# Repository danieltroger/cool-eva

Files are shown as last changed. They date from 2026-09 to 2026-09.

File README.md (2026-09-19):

# Cool Eva

Telemetry for a **watercooled 2021 Energica Eva Ribelle**. A Raspberry Pi inside the bike logs the temperatures of a custom watercooling loop on the battery pack, **plus** the bike's own battery / charge / cell / drive telemetry read straight off the CAN bus — all into an encrypted, write-only ride log, surfaced as a live phone dashboard and (after decryption on the laptop) a Grafana dashboard for post-ride analysis.

## Hardware

- **Raspberry Pi Zero 2 W** running the app as a `systemd` service (Node.js, runs as root).
- **[8devices Korlan USB2CAN](https://shop.8devices.com/usb2can/korlan/)** plugged into the bike's OBD port → `can0` (in-kernel `usb_8dev`, no driver install). 500 kbit, 11-bit. The app reads broadcast frames _and_ actively polls standard OBD-II PIDs (**read-only** — no diagnostic writes).
- **2× MAX31865 + PT100 probes** over SPI — coolant **in** and **out** of the custom battery watercooling loop. **Optional**: this is the one piece of hardware most Energicas don't have. Without it everything else works and the coolant tiles simply don't appear.
- **Networking:** the Pi joins my **phone's hotspot**, so it's reachable at **`http://cool-eva.local`** from the phone's browser. It's a bit janky (have to open hotspot page in phone settings for ~20s at the start of every ride), but it works for an at-a-glance dash while riding/charging.

### If you have a stock Energica

The Korlan alone gets you most of this. Everything under [What it logs](#what-it-logs) works on a stock, unmodified bike except the sections explicitly marked otherwise — no watercooling loop, no probes and no BMS reflash required. Set `COOLANT_ENABLED=0` and the coolant probes are never attempted.

Two caveats worth knowing before you spend money:

- It is developed against a **2021 Eva Ribelle**. The pack shape is hardcoded in places — 81 cells in 11 modules, a 400 A discharge and 120 A regen ceiling, a 130 kW power bar — and nothing detects a mismatch. On another bike in the same pack family the readings are right and those scale limits may not be; on a differently-packed model (Experia) treat the whole thing as untested. Reports welcome. The **VCU parameter names are not** in that category any more: all 28 of Energica's parameter tables are shipped and the bike's own `TABLE_TYPE` picks one, so [that half works on your bike](#vcu-parameters-by-name) whichever it is — and if your table is newer than the 28, [adding it is one command](#adding-your-bikes-vcu-parameter-table).
- The bike's **CAN bus is not a toy**. This app only ever reads, but it does transmit standard OBD-II _read_ requests to do so (see [Notes](#notes)). If you would rather it never spoke at all, `OBD_ENABLED=0` makes it passive-only.

## Setup

From a blank SD card to a dashboard. Steps 1–5 are the Pi, step 6 is your laptop, and **step 6 is the one people skip and regret** — without it the dashboard works perfectly and nothing at all is saved.

**1. Flash Raspberry Pi OS (64-bit).** In Raspberry Pi Imager, open the gear icon and set:

- **hostname `cool-eva`** — this is what makes `http://cool-eva.local` work. Skip it and your Pi is `raspberrypi.local`.
- **Enable SSH**, with a password or your public key. There is no screen on the bike, so this is the only way in — including for every future update.
- **Wi-Fi: your phone's hotspot** (SSID and password), so it connects on the road. Add your home Wi-Fi too, from the Pi later, or you'll be swapping the card to get it back.

**2. Join the phone hotspot** (if you didn't set it in the Imager). Bookworm uses NetworkManager:

```bash
sudo nmcli device wifi connect "<your hotspot SSID>" password "<password>"
sudo nmcli connection modify "<your hotspot SSID>" connection.autoconnect yes
```

On iOS you have to **open Settings → Personal Hotspot and leave it on screen for ~20 s** at the start of a ride, or the phone won't accept the join. That is an iOS behaviour, not something this app can fix. The Pi Zero 2 W radio is **2.4 GHz only**, so a 5 GHz-only hotspot is invisible to it — on an iPhone 12 or later, Apple's own fix is Settings → Personal Hotspot → **Maximize Compatibility** — which Apple notes costs some hotspot speed and Wi-Fi security.

To add a **second** network later (home Wi-Fi, an Airbnb) while you are sshed in over the first, use `nmcli connection add` rather than `nmcli device wifi connect` — the latter activates what it creates and drops the session you are typing into. Exact command: [INSTALL.md §8](INSTALL.md).

**3. Install Node 24.** Raspberry Pi OS's `apt` Node is far too old — the app is TypeScript run directly, which needs `--experimental-strip-types` (Node 22.6.0 at the very oldest; 24 is what this is tested on).

```bash
curl -fsSL https://deb.nodesource.com/setup_24.x | sudo -E bash -
sudo apt install -y nodejs
node --version   # must be v22.6 or newer
```

**4. Clone and install.**

⚠️ **Give the Pi more swap first.** `npm install` compiles three native modules (`better-sqlite3`, `socketcan`, `spi-device`), which takes **several minutes** on a Pi Zero 2 W and wants more than the stock 512 MB — without it the build is OOM-killed and it looks like a crash rather than a memory problem. About 3 GB. How, for both Bookworm and Trixie: [INSTALL.md §2.5](INSTALL.md).

```bash
git clone https://github.com/<your-fork>/cool-eva.git ~/cool-eva
cd ~/cool-eva
npm install
```

Nothing else to do for those compiles: the repo ships an `.npmrc` allowlisting the four packages with install scripts, because **npm 12 and newer refuse to run them** otherwise and you get a tree with no `.node` files. Version boundaries, how to tell whether your modules actually built, and the measurements: [`docs/pi-install-prerequisites.md`](docs/pi-install-prerequisites.md).

**5. Only if you have the coolant probes: enable SPI.** `sudo raspi-config` → Interface Options → SPI → Yes, then reboot. **Don't enable it if you have no probes wired**: with SPI on and nothing attached the reads succeed and return −242 °C forever. The app notices and retires the probe after a minute, but it's noise you don't need.

**6. Generate the ride-log keypair — on your laptop, not the Pi.** Nothing is persisted until the Pi has a public key. See [Encrypted ride log](#encrypted-ride-log) for why it works this way.

```bash
# on the LAPTOP, in a clone of this repo
node --experimental-strip-types scripts/generate-log-key.ts
# back the PRIVATE key up now (password manager) — it is the only thing that
# can ever read your logs, and there is no recovery path
scp ride-log-key.public.pem pi@cool-eva.local:/home/pi/cool-eva/
```

**7. Install the service** (back on the Pi):

```bash
sudo $(which node) --experimental-strip-types scripts/setup-service.ts
sudo journalctl -u cool-eva -f    # follow the logs
```

The installer refuses to run on too-old a Node, removes the old `thermometer` unit if you're upgrading, and tells you if the ride-log key is still missing. In the log you want to see `ride-log: encrypting to …`; if you see the `NO PUBLIC KEY` banner instead, step 6 didn't land.

Then open **`http://cool-eva.local`** on your phone.

## What it logs

Everything is logged **on change** (so steady values don't spam the log) into the encrypted ride log — see [Encrypted ride log](#encrypted-ride-log).

| Group | Signals | Source |
| --- | --- | --- |
| **Coolant** (custom loop) | `coolant_in`, `coolant_out` (°C) | MAX31865 PT100 |
| **Cooling fan** (custom loop, `FAN_ENABLED=1`) | `fan_duty_pct` (%, what the bridge is being given), `fan_target_pct` (%, what was asked for — the two differ only during a kick-start), `fan_driver_enabled` (1 = both IBT-2 enables HIGH, 0 = standby), plus `fan_auto_mode` (1 = the temperature curve is driving, 0 = the slider is) and the two codes that say why the curve chose what it chose, `fan_auto_reason` and `fan_temp_input`. Every one is what the Pi **commanded or decided**, never what it measured: this fan has no tacho and the current-sense pins are unconnected, so nothing here can tell you the rotor is actually turning. Written on change like everything else, which for a fan held at one duty means nothing for an hour. See [`docs/fan-control.md`](docs/fan-control.md) | Pi hardware PWM0 + `pinctrl` |
| **Battery / BMS** | `batt_temp_lo`, `batt_temp_hi` (°C, always the **true** pack temperature), `batt_temp_lo_vcu`, `batt_temp_hi_vcu` (what the VCU and dash read — lowered once a DC-derate config is flashed, by an amount that depends on the config; under the current bounded clamp they read 35 °C throughout the 35–54 °C band and the true temperature either side of it), `soc` (%), `soh` (%), `pack_v` (V), `pack_a` (A), `pack_kw` (kW), `allowed_discharge_a`, `allowed_regen_a` (A), `pack_resistance_mohm` (mΩ) | CAN `0x200`/`0x202`/`0x206`/`0x660` |
| **Cells** | `cell_min_mv`, `cell_avg_mv`, `cell_max_mv`, `cell_spread_mv`, `cell_deviation_mv` (the BMS's own ΔV), `cell_lowest_v_idx`, `cell_highest_v_idx` (which cell is at each extreme _right now_ — at a few mV of spread that ranking is noise, not a health verdict), `cells_connected`, `cell_voltage_sum_v` | CAN `0x203`/`0x205`/`0x207` |
| **BMS state & faults** | `charge_state` (raw System State bitfield) + decoded `bms_state_*` (discharge / charge / balancing / trickle / idle / charge complete / maintenance), `bms_error_flags`, `bms_warning_flags` (raw words) + booleans for the ones worth acting on: cell over/under voltage, over temperature, leak detected, leak detection failed, contactor faults, low SOC, balancing required. Plus `bms_leak_detect_inhibit` — Energica's own `V_IMD_DISABLE`, the vehicle **commanding** the insulation monitor off for the duration of a DC session, since it cannot run against a station-driven bus. It is 1 while a DC session exists in 99.933 % of 156 931 frames and 0 whenever one does not in 100.000 % of 810 934 | CAN `0x201`/`0x605` b7 |
| **Isolation** | `iso_test_1`, `iso_test_2`, `iso_test_total` (10-bit ADC, 512 = ideal), `bms_io_state`, `lmu_comm_warnings` | CAN `0x207`/`0x206` |
| **Charge** | `charge_state`, `dc_v`, `dc_a`, `mains_v`, `mains_a`, `charge_limit_a`, `dc_charge_limit_selected_a`, `charger_enabled`, `charger_max_dc_v`, `charger_max_dc_a`, `bms_post_processor_1` (purpose unknown, logged raw so a ride can name it), `fast_dc_contactor` — the DC fast-charge contactor monitor (Energica's `V_FASTDC_MON_SW`, and the analog wire `A020_FCHG_MON`). It is 1 only on DC: across 1.1 M frames of `0x102` it was set in exactly one interval, a 17-minute DC session that took the pack 30 → 42 %, and 0 through every AC charge including a 48-minute one at 14 A. It rises ~190 ms before `charger_enabled` and ~470 ms before the first amp, which is what a contactor monitor should do. **From the charge manager** (decoded 2026-08-19 across 29 charge sessions, 18 AC and 11 DC — that ECU is only awake with a cable plugged in, and the standing assumption that this meant DC only was wrong; reconciled against Energica's factory DBC on 2026-08-20, see `docs/charge-manager.md`): `fast_dc_target_a` — the DC current the vehicle **asks the station for**, and the only DC-side current on this bus, since a DC session sends no `0x305`/`0x306` at all and `charge_limit_a` reads 0 through one; `fast_dc_target_v`, the DC target voltage that goes with it, which sits a median 13.4 V above the pack; `fast_dc_limit_a` and `ac_supply_limit_a`, the ceilings the **station** offers for each path, each 0 while the other path is live; `fast_dc_limit_max_a` and `fast_dc_limit_max_v`, the vehicle's own configured 75 A and 371 V; `dc_charging` / `ac_charging`, which say current is _flowing_; `charge_type` (1 = AC, 2 = DC) and `charge_manager_state`, which say a _session exists_ — `0x610` b7 reads `0x23` on DC in 99.974 % of 151 096 frames and `0x02` on AC in 99.999 % of 784 599, the cleanest AC/DC discriminator on the bus; plus `charge_manager_status`, `charge_manager_soc` (the SOC the VCU reports outward to the station, which is free to disagree with the BMS's) and `charge_manager_error_src` / `charge_manager_error_code` — the charge manager's own fault code, which `src/can/vcu-flags.ts` had recorded as not broadcast anywhere and which has fired three times in the archive | CAN `0x201`/`0x305`/`0x306`/`0x10a`/`0x300`/`0x102` b3/`0x121`/`0x605`/`0x610`/`0x615`/`0x620`/`0x625` |
| **Energy** | `inst_consumption_wh`, `residual_energy_wh` (available energy), `bms_remaining_energy_raw`, `remaining_ah`, plus the hub's own trip figures: `range_km`, `avg_consumption_wh_km`, `km_per_kwh`, `kwh_per_100km` (the last two emit nonsense at a standstill and are gated on the dashboard) | CAN `0x025`/`0x10A`/`0x205` + hub |
| **Energy, the cluster's range** | `range_can_km` — CAN `0x412` b2-b3 at 2 Hz, the instrument cluster's own range estimate, computed on the cluster and the only range that survives the Bluetooth link being down. Same bound as `range_km` so the two compare directly. See `docs/can-0x412.md` | CAN `0x412` |
| **Energy, the bike's own figures** | `km_per_kwh_can`, `kwh_per_100km_can` — the VCU broadcasts its instantaneous consumption at 10 Hz, both ways round, and the two are exact algebraic reciprocals of each other, which is what pins the frame's layout and both scalings with no bike involved. Separate keys from the hub's pair above, for the same reason `odometer_can_km` is separate. **Sparse on purpose**: the VCU saturates the pair whenever consumption is undefined — standing still, or coasting — and those frames are dropped rather than logged as 65 kWh/100 km. 🟡 `km_per_kwh_100m_can`, `kwh_per_100km_100m_can` are the 100 m averages; a garage lap only ever produced two values for them, so their scaling is carried over by position rather than confirmed. See `src/can/consumption.ts` | CAN `0x10B` |
| **Drive** | `throttle_pct`, `speed_kmh`, `motor_rpm`, `motor_load_pct`, `dist_since_clear_km`, `motor_torque_nm`, `motor_power_kw` (over Bluetooth; the same records are on CAN `0x410` sub-type 3 and are logged separately as `motor_torque_can_nm` / `motor_power_can_kw`), `odometer_km`, `trip_km`, `vehicle_state`, `vehicle_substate` | CAN `0x109` + OBD-II `0D`/`0C`/`04`/`31` + hub |
| **Drive, the cluster's own numbers** | `dash_speed_kmh`, `motor_torque_can_nm`, `motor_power_can_kw` — CAN `0x410` sub-type 3, the records the instrument cluster transmits and the hub carries over Bluetooth. Torque and power are the Bluetooth pair off the bus instead, logged separately so the transports stay comparable. 🟡 `dash_speed_kmh` is **not** `speed_can_kmh`: the same geared driveline speed through a ~40.26 divisor against 42.0, a median ratio of 1.0433 over 42 705 paired samples, which puts it ~8 % above GPS where a legal speedometer sits. Whether it is literally the number on the dash is **unconfirmed** — one glance at the speedo against the phone settles it. See `docs/can-0x410.md` | CAN `0x410` |
| **Drive, second opinion** | `speed_can_kmh`, `motor_rpm_can`, `odometer_can_km`, `odometer_pulse`, `rolling_backwards` — deliberately **not** merged into the keys above, because comparing the two over a ride is the point and one key with two writers just flaps. Plus the inverter's own limits `current_max_out_a`, `current_max_regen_a`. 🚨 `current_other_a` is **gone**: 0x109 b6-7 is not a current at all — it is Energica's ride-map-and-events bitfield, and the .xdbc reading produced 5069 A. It is replaced by `tc_event` and `eabs_event`, the VCU's own traction-control and eABS interventions, ✅ confirmed by behaviour (`tc_event` fires at 77 % throttle and +138 Nm median, and separates torque even within one throttle band) | CAN `0x104`/`0x109` |
| **ABS & brakes** | All ten signals Energica's own `ParseABS_INFO` names. `wheel_speed_front_kmh`, `wheel_speed_rear_kmh` — the ABS module's own two wheels, the only front-wheel measurement on the bike, and ✅ **calibrated against GPS to ~1 %**: Energica's 0.05625 km/h per count is 3.6/64, a wire encoding, and it stands (an earlier claim here that the channels read ~4 % off and disagreed by ~9 % was an artefact of a walking-pace garage lap, and is withdrawn). `front_brake_pressure_bar` — **brake line pressure**, which nothing else here carries; ✅ front-specific by measurement, held at 0 bar through 434 frames of rear-pedal-only braking while the front lever alone drove it to 8. `abs_warning_lamp` (a two-bit field, 0…3, not a flag — it is the self-test, and it needs road speed to clear). Plus six flags: `abs_event`, `abs_rear_control_active`, `abs_front_control_active` — ✅ all three measured firing, over **162 event frames in 61 interventions across 15 captures** (the whole archive, 565 376 frames of this ID, rescanned 2026-08-20); `abs_front_sensor_fault`, `abs_rear_sensor_fault`, `abs_front_pressure_validity` — ⚠️ never seen set in any of those 565 376 frames, which is what a healthy bike with a working decode looks like, not evidence against the bit positions. ❌ **What causes an intervention is NOT settled and the earlier regen-slip reading here is withdrawn:** the throttle is _open_ at 117 of the 162, and traction control is refuted as the alternative — drive torque is cut in 0 of 93 throttle-open interventions. The braking population (35 of 162 carry front brake pressure, 1–21 bar) is the only one whose cause the throttle, the torque and the wheel divergence all agree on. ❓ `abs_front_pressure_validity`'s **polarity is unestablished** and the pressure is deliberately not gated on it. ⚠️ The pressure's "bar" is Energica's stated unit with nothing on the bus to check it against. The ABS is physically on the **DTB** bus, not the VDB one we tap — `0x0A0` only reaches us because the VCU gateways it — so these ten are the entire ABS interface and no diagnostic sweep can ever add to them. See `src/can/abs.ts` | CAN `0x0A0` |
| **Torque, and the redundant sensor pairs** | `drive_torque_cmd_nm`, `drive_torque_feedback_nm` — what the inverter was asked for and what it delivered, in Nm; the 0.1 Nm scale is stated by Energica and independently forced by the power balance. `throttle_sensor_a_raw`, `throttle_sensor_b_raw` — the throttle position sensor's two channels as 12-bit counts, which track within [−143, 0] of each other; a divergence is what `P0120`/`P0121` exist to report. `speed_redundant_a_raw`, `speed_redundant_b_raw` — the safety micro's two road-speed channels, byte-identical in 88 % of frames. ⚠️ Those last two are **raw counts with no unit**: they correlate with road speed at r = +0.997 but no round scale survives the capture (~109 counts per km/h, which is nothing in particular), so they are not published as km/h. See `src/can/drive.ts` | CAN `0x02C`/`0x127`/`0x125` |
| **VCU error & status flags** | `vcu_flags_low`, `vcu_flags_high` — the VCU's own 64-bit flag word, logged raw in two halves so no flag is ever lost, plus booleans for the ones worth an alert: `vcu_err_charge_manager`, `vcu_err_check_modules`, `vcu_check_modules_status`, `vcu_warn_soc_misaligned`, `vcu_12v_power_good`, `vcu_err_system_fault`, `vcu_err_system_fatal_fault`, `vcu_err_system_blocking_fault`, `vcu_err_battery_ot`, `vcu_err_motor_ot`, `vcu_err_drive_ot`, `vcu_err_leak_detect`. **`vcu_err_charge_manager` is the useful one**: it is broadcast, so a charge-manager fault becomes visible passively. ✅ It **has** fired — set in **3 563 frames across four events**, rising 0.162 s after `0x610` publishes an error code in three of them, and held 269.7 s with no code at all in the fourth. ⚠️ Two claims here were wrong until 2026-08-21: that the charge manager's error telemetry "is not broadcast at all and needs a diagnostic session" (`0x610` broadcasts it), and that this bit reads "0 in all 105 736 captured frames — never seen to fire", which was a statement about the sample. Seven of the other booleans genuinely have not been seen to fire. Four bits have been watched moving, one of them landing on the exact second a DC session was unplugged. See `src/can/vcu-flags.ts` | CAN `0x100` |
| **12 V supply** | `psu_12v_mv` (validated against the engineering menu), `psu_12v_lowpower_mv` (a second rail that sits at ~9.03 V despite the name), `psu_12v_load_ma` — the DC-DC's own output current, confirmed by every consumer that switched during a lap showing up as a step of the right size: high beam +1788 mA, blinker +1030 mA, brake light +693 mA. 🟡 The mA scale itself is inferred from the millivolt rail beside it, not measured. `P_TEMP` in the same frame is deliberately **not** decoded — Energica's own equation for it gives 390 °C. See `src/can/psu.ts` | CAN `0x501` |
| **GPS** | `gps_lat`, `gps_lon` (emitted only when both axes arrived in the same sub-frame cycle — a half-fresh fix is withheld, not blended), `gps_altitude_m` (16-bit two's complement, so −1 m reads as −1 m), `gps_speed_kmh`, `gps_course_deg`, `gps_satellites`, `gps_fix`, `gps_epoch_s` (satellite UTC, logged raw — the Pi has no RTC, so a no-network boot's timestamps stay repairable). Arrives over **both** transports; position is not Bluetooth-only | CAN `0x410` + hub over BLE |
| **Powertrain temps** | `inverter_igbt_min_c`, `inverter_igbt_c`, `inverter_igbt_max_c`, `inverter_gate_c`, `motor_temp_c` (°C) — separate sensors from the OBD poller's `bike_coolant_temp`, and they move differently under load | CAN `0x020`/`0x022` |
| **Controls & vehicle state** | `high_beam_lamp`, `low_beam_lamp`, `horn` (which the All page latches like a button — a horn blast is as brief as a press), `energized`, `go_request`, `go`, `key_on`, `stand_up` (sidestand retracted), `ignition_button`, `throttle_on`, `moving`, `cruise_active` (cruise control armed — inferred, not in any vendor table, from two events where it followed the cruise ON/OFF button by half a second). ⚠️ The two beam lamps were logged as `charging` and `charge_port_unlocked` until 2026-08-16, on a rider-made `.xdbc`'s word: **both names were simply wrong.** Each agrees with its beam switch in `0x102` b0 across all 1 103 000 frames of the capture corpus with zero disagreements, and the old `charging` bit reads 0 through every real charge. Old rows are correct readings under a wrong name, so the Grafana State panel unions the old key into each lane and the history stays continuous. ⚠️ `brake` (front **or** rear) was logged in this row from June until 2026-08-30 and is **gone**: it was computed from `front_brake` \| `rear_brake`, which have been logged separately since 2026-08-19, and this log stores the bits that were measured rather than combinations a reader can recompute. The rows already written are still correct readings, so the State panel's Brake lane reads them up to the day the halves start and the OR of the halves after it | CAN `0x102` |
| **Rider controls** | Everything the rider's hands and feet move, in one group so the dashboard can show them together. The **buttons**: `btn_mode_left`, `btn_mode_right`, `btn_mode_enter`, `btn_indicator_cancel` (left pod, as VCU discretes), `btn_set_back`, `btn_cruise_enable`, `btn_cruise_set`, `btn_heated_grip` (dashboard inputs) — momentary and short, the median press measured 140 ms and the shortest 30 ms. The **held states**, added 2026-08-19: `high_beam` (b0 bit 6, the switch, which is also how you change dashboard screens), `blinker_left`, `blinker_right` (the lamp outputs, which flash rather than stay on), `front_brake` and `rear_brake` (b2 `0x20`/`0x40`, two keys because they are two circuits — captured frames carry both at once, and the rear pedal alone leaves `front_brake_pressure_bar` at 0). The dashboard latches all of them for 600 ms, counts presses, and describes a hold by its duration instead once it passes a second; see [The dashboard](#the-dashboard). Since 2026-08-30 that treatment is chosen per KEY rather than per group (`public/lib/latched.js`), so `horn` and `ignition_button` — momentary, and in `controls` because that is where their history is — get it without being moved between groups, which `rides.db` would never forget. **Confidence varies per bit and is written down next to each one in `src/can/vcu-digitals.ts` (the `0x102` b0 bits) and `src/can/decode.ts` (the `0x400` ones)**: indicator-cancel and the two cruise buttons are confirmed by what they correlate with, the MODE pair is confirmed as menu buttons **and, since 2026-08-19, as left-vs-right** (by instructed press: eight presses of each button in turn, every block fenced by a counted number of indicator-cancel clicks so the capture labels its own blocks), `btn_set_back` was first seen set that same day, and `btn_heated_grip` has still never been seen set at all — which is expected, since this bike has no heated grips. The b0 indicator **switches** are deliberately not decoded — vcu-digitals.ts records that b0 bit 3 is right and bit 4 is left, measured over 14 650 573 frames, for whenever something needs them | CAN `0x102` b0/b2 + `0x400` b2 |
| **Attitude** | `attitude_roll_deg` (positive = leaning right), `attitude_pitch_deg` (positive = nose-down, i.e. braking) — the attitude sensor's two derived angles in degrees, **not** the accelerations the `.xdbc` calls them. Gravity-referenced and not gyro-fused, so a steady corner reads ≈0 and pitch mostly reports braking rather than gradient; they say which way is down, not how far over the bike is. Logged as `accel_lateral_raw`/`accel_frontal_raw` before 2026-08-15 — same numbers, in 0.1°. See `src/can/attitude.ts` | CAN `0x102` b4-7 |
| **Security** | `key_fob_id` (which fob started the bike — part of why the log is sealed), `keys_paired` (read once at startup from the E-LOCK ECU) | CAN `0x480` + E-LOCK `0x791` |
| **OBD-II (1 Hz)** | `bike_coolant_temp` (motor/coolant °C), `oil_temp` (°C), `ambient_temp` (°C), `aux_12v` (V), `soh_pid` (%) | OBD-II `05`/`5C`/`46`/`42`/`5B` |
| **Trouble codes** | `mil_on`, `dtc_count` (stored, per PID `01`), `dtc_stored_count` (the mode-03 list's own length — the same number down a second path), `dtc_list_count` (the bike's _active_ list, a different thing), `dtc_unrecognised_count`, `freeze_frame_dtc` (the code that lit the lamp), plus one 1/0 signal per code Energica documents. `dtc_pending_count` and `dtc_permanent_count` are written **only if** modes 07/0A ever answer — on this bike they never have, and their absence is the honest record of that. See [Trouble codes](#trouble-codes) | OBD-II `01`/`02` + **mode 03** · CAN `0x410` |
| **Service counters** | `time_since_clear_min` (monotonic ⇒ an hour meter), `warmups_since_clear`, `dist_with_mil_km`, `time_with_mil_min` | OBD-II `4E`/`30`/`21`/`4D` |
| **Waypoints** | `waypoint_seq`, `waypoint_lat`, `waypoint_lon` — written only when you ask, from the dashboard button or Siri. See [Saving a waypoint from Siri](#saving-a-waypoint-from-siri) | `GET /waypoint` |

### Signals that need the custom BMS config

Everything in the table above works on a **stock, unmodified Energica** — including the isolation readings on `0x207` and the allowed-current limits on `0x202`, which the BMS broadcasts as shipped.

The frames below only exist once the pack's LiBAL BMS has been reflashed with the custom config. On a stock bike they simply never arrive, so **these signals being absent is normal, not a fault**:

| Group | Signals | Source |
| --- | --- | --- |
| **Per-cell voltages** | `lmu1_cell1_mv` … `lmu11_cell7_mv` — the individual cells, multiplexed by module at 20 Hz. Known gap: cells 4-8 of LMU 1 and 2 never get sampled, because the CAN transmit order is phase-locked to the BMS's module poll (see `src/can/decode-bms.ts`) | CAN `0x662`–`0x664` |
| **Per-module temps** | `lmu1_bat1_c`, `lmu1_pcb1_c`, `lmu1_pcb2_c` … — each module's battery and board sensors, keyed off the same module number as its cells. Modules 6 and 8 have no battery sensor enabled, so they never report one: configuration, not a fault | CAN `0x664` |
| **Module selector** | `lmu_cell_mux` — the raw module number the per-cell frames are currently carrying, logged so that "byte 0 isn't the LMU number after all" stays distinguishable from "the frames never arrived". Deadbanded to one row per boot | CAN `0x662`–`0x664` b0 |
| **Pack temps** | `pack_temp_avg` (°C), `lmu_temp_high_idx`, `lmu_temp_low_idx`; in the clamp config also the true `batt_temp_lo`/`batt_temp_hi` plus the clamp's own arithmetic (`clamp_gate`, `clamp_amount`, `batt_temp_hi_vcu_echo`) | CAN `0x660` |
| **Energy / hours** | `bms_remaining_energy_wh` (1 Wh resolution), `bms_uptime_min` (BMCU hour meter) | CAN `0x661` |
| **Cell limits** | `cell_cutoff_mv`, `cell_end_of_life_mv`, `cell_overvoltage_mv`, `cell_target_mv` — the thresholds the BMS is actually configured with, so nothing downstream has to hardcode them | CAN `0x665` |

> VIN and BMS writes are still **not** reachable from the OBD port (on the standard pins, haven't tried the other pins yet). Per-cell voltages **are** — they just have to be enabled in the BMS's own configuration first, which needs the vendor's BMS tooling and is not something this repo can do for you.

#### `CUSTOM_BMS_CONFIG` — set this only if you flashed the custom config

The custom config lowers the pack temperatures the VCU reads, so that its DC-charge derate knee — which starts at a reported 36 °C, far too early for a watercooled pack — is not reached while the pack is merely warm. How much lower is not a constant, and depends on which config is flashed. The newest one (`15-bounded-clamp`, built 2026-08-09 and not yet flashed — the bike currently runs `14-signbit-clamp`) is a **bounded** clamp: the true temperature below 35 °C, a flat **35 °C** from 35 to 54 °C, and the **true temperature again from 55 °C up**. That upper bound is the point — the VCU enters limp mode at 55 °C battery (`LIMP_B_TEMP`), and its predecessor `14-signbit-clamp`, which pinned the reading at 35 for _any_ temperature above 35, did not delay that protection so much as disable it. An earlier config shifted by a flat −15 °C instead; it broke charging and is retired. Whichever is loaded, this changes what `0x200`'s temperature bytes mean, so the app has to be told:

```bash
CUSTOM_BMS_CONFIG=1   # only with the custom BMS config flashed. Default: unset = stock.
```

**Leave it unset on a stock bike** — `batt_temp_lo` / `batt_temp_hi` then come straight off `0x200`, as they always have, from about five seconds after the BMS starts talking (see below). With it set, those keys come from `0x660` instead and `0x200`'s (shifted) view is logged separately as `batt_temp_lo_vcu` / `batt_temp_hi_vcu`. Either way `batt_temp_lo` / `batt_temp_hi` always mean the **true** pack temperature, so the history stays one continuous series.

The flag is only a hint about what to expect — the frames on the bus win. Which config is live can only be read off what arrives (a long `0x660` means the offset config, a short one means the extended config without it, and no `0x660` at all means stock), so **the true-temperature keys are not written at all until that is settled**, which takes up to 5 s from the first `0x200`. A gap is deliberate: `batt_temp_lo` / `batt_temp_hi` are never allowed to carry the shifted view, and everything is logged on change, so a few seconds of silence costs nothing while a wrong value would be sealed into the ride log for good. `batt_temp_lo_vcu` / `batt_temp_hi_vcu` are unaffected and log from the first frame.

Get the flag wrong in either direction and the app says so:

- flag unset but the custom frames turn up → loud error, and the keys take `0x660`'s true values;
- flag set but no `0x660` ever arrives → warning, and `batt_temp_lo` / `batt_temp_hi` stay **unlogged** rather than falling back to `0x200`, whose bytes are the shifted view under that config. Unset the flag if the pack really is stock.

Nothing else in the app is affected by this flag; every other decode is correct on both configs.

## How it works

```
MAX31865 probes ─┐
                 ├─► signals (log-on-change) ─► sealed ride log ─► /dl ─► laptop ─► SQLite ─► Grafana
Korlan can0 ─────┤                            └─► live state ─► WebSocket ─► phone dashboard
  · broadcast decode (0x200, 0x203, …)         (the bike holds only a public key:
  · OBD-II poll @1 Hz (0D, 05, 42, …)            it can seal history, never read it)
  · GPS on 0x410
Energica BT hub ─┘
  · torque/power, odometer, vehicle state
```

- `src/can/` — `socket` (can0 bring-up + raw channel), `decode`/`decode-bms` (broadcast frame decoders, pure), `pack-temperature` (picks which frame owns the true pack temperature, since that depends on which BMS config is flashed), `obd` (OBD-II poll loop), `signals`/`registry` (log-on-change core).
- `src/gps/` — `decode` (the hub's GPS message, pure; shared by CAN `0x410` and the BLE link, which send byte-identical frames), `clock-gate` (whether a satellite time may be stepped to — also pure, so `scripts/check-gps-clock.ts` can replay real sequences through it), `clock` (the I/O half: reads both clocks and runs `date -u -s`, because the Pi has no RTC).
- `src/ble/` — the Bluetooth link to the Connectivity Hub: `protocol` (framing + handshake, pure), `client` (D-Bus session), `adapter` (bring-up).
- `src/sensors/max31865.ts` — the coolant probes.
- `src/storage/encrypted-log.ts` — the only persistence on the bike: sealed, append-only, write-only. Every append is flushed to the card before it counts as written, because the Pi loses power with the bike and an unflushed one comes back as NULs — [`docs/power-cuts.md`](docs/power-cuts.md).
- `src/storage/durable.ts` — the flush recipe the four on-bike writes share.
- `src/db.ts` — SQLite schema (long/EAV: `signal` + `session` + `reading`). Now used **only on the laptop**, by `scripts/decrypt-log.ts`, to rebuild a plaintext DB from decrypted segments. `reading.ts` is a wall-clock stamp and `(session_id, seq)` is the write order; they are separate because the wall clock steps (see [Clock](#clock)), so `ORDER BY ts` is not the order the rows were written. Nothing queries the counter yet and no index covers it — it is recorded so the ordering is _recoverable_, and adding an index over 6.2 M rows is a decision for whoever first needs one.
- `src/http/` — `static` (serves `public/` from memory), `download` (`/dl`), `waypoint` (`/waypoint`), `status` (`/status`).
- `src/ws.ts` + `public/` — the live phone riding dashboard (see below).
- `src/index.ts` — wires it all together.

## The dashboard

Five screens, switched from the tab bar — or by **flashing the high beam three times**, which is the only control that works with both hands on the bars.

| Screen | For |
| --- | --- |
| **Ride** | GPS speed, power, pack and coolant temperatures, **coolant ΔT** with the I²R watts going in beside it, charge |
| **Hypermile** | Weakest cell's headroom above cut-off (instantaneous **and** sag-compensated), the BMS's 60 s cut-off timer, allowed current, rolling Wh/km, resistive loss, all 81 cells as a strip |
| **Charge** | A / V / kW, what the BMS is granting the charger, balancing state, cell spread trend, pack temperature, isolation |
| **All** | Every signal the bike is producing, grouped and filterable. Signals whose EDGES are the event render differently from the rest — the whole **buttons** group, plus `horn` and `ignition_button` by name (`public/lib/latched.js`): the handlebar buttons are momentary, and the median press is 140 ms — one or two frames of a 60 Hz display — so a raw 1/0 readout would flicker and be gone. Each button tile latches lit for 600 ms after the bit drops and keeps a press count with the time of the last one. Trust the count over the light: a count that climbs while the tile never visibly lights is a working button whose flash the browser dropped. Since 2026-08-19 the group also holds the indicators, the high beam and the two brakes, which are **not** momentary, so a tile down for over a second says how long instead ("held 4 s") — a clock reading rather than a list of which keys are held states, because the populations overlap in both directions. That also retired the old "a tile stuck lit with a count of 1 is a fault" rule, since it is now what a squeezed brake lever looks like; the duration under the tile is what separates a lever from a stuck bit. The blinkers are the one hand-named exception, because they are lamp outputs that a running indicator toggles, so counting rising edges would overreport a signalled turn by about 6×. The measured durations, the blink rate and the gap histogram behind the thresholds live next to the constants they justify — `public/lib/press.js` and `public/lib/flasher.js` — rather than being restated here |
| **Faults** | Stored and active trouble codes, named from Energica's own table, with the history behind each. Carries the ⚠ itself, so a code appearing mid-ride is visible without costing space on the screen you're looking at |

**Ride** and **Charge** are what you leave it on; Hypermile and Charge the bike picks for you. It switches to Charge when the BMS reports a charging state, and to Hypermile below 5 % SOC **or** when the weakest cell drops within 150 mV of cut-off — SOC near empty comes from an OCV table that was never re-characterised for these cells, so it can't be the only trigger. The switch is edge-triggered: once it has moved you, you can move back and it stays put.

Design notes for the hypermiling numbers are in `HYPERMILING.md`; the derivations all live in `public/lib/derive.js` and nothing derived is ever logged.

### No build step

`public/` is plain ES modules that the browser runs exactly as committed — deploy stays `git pull` + restart, with nothing to rebuild and no dist to go stale, and you can edit a file over ssh in the garage. The one dependency is [VanJS](https://vanjs.org) (5 kB, vendored in `public/vendor/`), which is signals over real DOM with no virtual DOM anywhere.

It is still type-checked: `tsconfig.json` sets `checkJs`, and the modules carry JSDoc types that **import the server's own `DashboardMessage` from `src/ws.ts`**. Change the wire shape and `npm run typecheck` fails — which is what stops the two drifting apart.

Bad readings are filtered rather than drawn. Across 7.6 M logged rows the bike has produced `coolant_in` at −242 °C (59 450 rows), `coolant_out` at 988 °C (40 351), `0xFFFF` cell voltages and `high_beam` reading 193 — so `public/lib/bounds.js` gates every signal against a physical range, and a rejected value shows as **sensor fault** instead of being clamped into something plausible.

### Developing it without the bike

```bash
node --experimental-strip-types scripts/replay-capture.ts <capture.log> --speed 4 --skip 60
# → dashboard on http://localhost:8080, fed by the real decoders
```

Replays a `candump -tA` capture through the actual decode path, so what's on screen has taken the same route it does on the Pi.

The captures this was developed against are one motorcycle's ride history and aren't in the repo, so you'll need your own: `candump -tA can0 > capture.log` on the Pi while the bike is awake, and anything from a few seconds up will do. `scripts/decode-dtc-response.ts` does run standalone — it replays a real, committed trouble-code transfer and needs no capture at all.

### Checking it without the bike

```bash
npm test        # about a second; no bike, no can0, no capture
```

Runs the self-checks that replay **committed** fixtures: the trouble-code transfer above, and `scripts/check-vcu-params.ts` (parameter table, request encoding, framing, the live reads, interpretation, the snapshot diff, and the KWP transport against a simulated micro). `scripts/check-button-decode.ts` replays 25 real `0x102`/`0x400` frames, plus 2 constructed ones that prove only that the decoder is self-consistent, — including the two the cruise buttons were ever recorded on, the one the fast-charge contactor closed in, the frame the right indicator lamp lit on, and the rear-brake-only frame that closed an open question in `src/can/abs.ts` — and also guards the three ways this feature could be switched off without anything else failing: `0x400` dropping out of the kernel RX filters, a button key missing from the registry, and a deadband on a 0/1 signal, which stops it logging after the first sample and does so silently. It additionally walks all 256 values byte 2 can take and asserts that the two brake bits stay on 0x20 and 0x40 respectively, because a mask edited by one drifts on a single value nobody thought to capture. `scripts/check-all-view-tiles.ts` covers which tile each signal gets on the All page, and `scripts/check-brake-lane.ts` runs the ride-summary dashboard's own Brake query against a built database, since that lane is now an OR of two log-on-change series carried forward — a shape whose obvious spelling latches to yes and never comes back down. `scripts/check-freeze-frame.ts` cross-checks Energica's 155 per-fault field shortlists against `src/diagnostics/dtc-table.ts` — a real check across two independently sourced tables, which is why it knows about the two water-pump codes they disagree on — and then replays 31 freeze-frame transfers through the reassembler and decoder — 29 of them the replies the bike actually sent, plus 2 constructed (`P0A07` and `P0514`) whose invented values exercise decode paths the captures don't reach — a zero-current open circuit, a negative int16 and int8, the ×0.1 scaling and the `(X/2)−40` air temperature. Those 2 prove only that the decoder is self-consistent; the 29 captured ones prove the wire format. The shapes the bike never sent — a refusal, a wrong-component answer, a short consecutive frame mid-transfer — are checked separately, frame by frame, rather than replayed as transfers. It also runs `scripts/generate-grafana-dtc.ts --check`, which compares the fault-code table Grafana carries inline against `src/diagnostics/dtc-table.ts` — a copy that once went stale for months without anything on screen looking wrong. CI runs the same command on every PR, so a change that breaks a decoder, the parameter table or that dashboard goes red rather than green.

`scripts/check-can-decoders.ts` covers the broadcast decoders the same way, from a handful of frames copied byte for byte out of a real capture — and then checks three things about the decoder set that replaying cannot see. The important one is the **RX filter**: `STREAM_IDS` sets the kernel's CAN filters, so an ID missing from it never reaches the decoder and there is no symptom at all — no error, no warning, just a signal that never appears, which looks exactly like a bike that never sent it. That has already cost time here once, on `0x400`. The check probes the decoder across the whole 11-bit ID space and fails if anything that decodes is missing from the filter. It also fails if a decoder emits a key with no registry entry, and if any 1/0 flag carries a deadband of 1 or more — because `|1 − 0| > 1` is false, so such a signal logs once after boot and then goes silent forever.

There is no test framework — `scripts/run-checks.ts` runs each check as its own process and fails if any of them does, which keeps them runnable by hand exactly as their own headers document. Anything that opens a CAN socket, wants root, or needs a local-only file is deliberately excluded; that list, with a reason for each, is at the top of the runner.

### Saving a waypoint from Siri

`GET /waypoint` stamps the current fix into the ride log and replies with one line of text, which Siri reads back. To set it up: **Shortcuts → new shortcut → Get Contents of URL → `http://cool-eva.local/waypoint`**, then add **Speak Text** with the result. Name it something like "Mark this spot" and it works from the handlebars.

A waypoint is stored as three ordinary signals (`waypoint_seq`, `waypoint_lat`, `waypoint_lon`), so it travels the normal path into the encrypted log and needs no change to the log format. It refuses to save on a fix older than 30 seconds, on an unsynced clock, or on a fix that is not a position on Earth, and says which rather than silently recording the wrong place — though a fix that is wrong while still being a legal coordinate is refused by none of those, only flagged later by the map ([#165](https://github.com/danieltroger/cool-eva/issues/165)).

**Seeing them again:** the route map dashboard draws waypoints as stars, with a table under it listing every one in the window and whether the surrounding track backs its position up; the menu sheet's Waypoints tile shows the last one's position and time. `docs/waypoints.md` covers the gate and what it cannot see.

## Running it

The app is the `cool-eva` `systemd` service on the Pi (Node 24, TypeScript run directly via `--experimental-strip-types`), serving `http://<pi>/` on port 80. First install is under [Setup](#setup); after that, deploying is a pull and a restart:

```bash
git pull && sudo systemctl restart cool-eva
sudo journalctl -u cool-eva -f    # follow logs
```

A restart no longer re-initialises a healthy can0: since #160 the service reads the interface first and leaves it alone when it is already configured the way it would configure it, so a deploy should stop punching a five-second hole in the raw capture. It still bounces the link when it genuinely needs reconfiguring — and because it no longer bounces one that merely _looks_ healthy, "restart the service" is no longer the way to kick a wedged adapter: `sudo ip link set can0 down` first, or use the dashboard's CAN-restart button. ⚠️ **Unverified until the first deploy after this shipped** — the bike was powered down when it was written, so the fixtures behind it are synthetic. [`docs/can-capture.md`](docs/can-capture.md) has the conditions, the residual hole and what that first deploy settles.

The dashboard menu's **Update** button does exactly that pull and restart from the phone, showing git's output. It runs the pull as the checkout's **owner** rather than as root — never `sudo git pull`, which poisons `.git` and makes the _next_ pull fail silently. [`docs/deploy.md`](docs/deploy.md) has the why; [INSTALL.md §3](INSTALL.md) has what to type.

> ⚠️ **Don't run `npm install` or `npm ci` on the Pi unless a dependency actually changed.** `package-lock.json` is generated on macOS, where `socketcan`'s Linux-only native build is skipped as an optionalDependency; installing against that lockfile on the Pi deletes the real one, and the service then dies on boot with `ERR_MODULE_NOT_FOUND: socketcan`. `npm install socketcan` will insist it's "up to date" even with `--force` — the fix is `rm package-lock.json && npm install` **on the Pi** (~4 min). A plain `git pull` never touches `node_modules` and is always safe.

The sealed ride log can be downloaded from `http://<pi>/dl` — short enough to type on a phone, and ~10x smaller than the old SQLite download. What crosses the wire is ciphertext: without the laptop's private key those bytes are noise. That is a claim about the **bytes**, not about the **transfer** — `/dl` is unauthenticated plain HTTP, so anyone on that network can pull the whole log and keep the ciphertext against the day the key leaks, and anyone in the middle can truncate it, because segments are sealed one by one and nothing signs the sequence. See [What this does and doesn't hide](#what-this-does-and-doesnt-hide). Decrypt it on the laptop (see below) to get a `.db` for Grafana.

### Configuration

Every option is an environment variable, and every default is what the bike in the photo runs. Set them in **`/etc/default/cool-eva`**, one `NAME=value` per line:

```bash
sudo tee /etc/default/cool-eva <<'EOF'
COOLANT_ENABLED=0
EOF
sudo systemctl restart cool-eva
```

Not in the unit file — `scripts/setup-service.ts` rewrites that every time it runs, which is exactly what you do to migrate a Pi or after a Node upgrade, and anything configured there would be silently discarded.

| Variable | Default | What it does |
| --- | --- | --- |
| `COOLANT_ENABLED` | on | `0` skips the MAX31865 probes entirely. Set this on a bike with no watercooling loop. |
| `FAN_ENABLED` | **off** | `1` drives the watercooling loop's radiator fan from the Pi's hardware PWM (an IBT-2 half-bridge on GPIO18) and serves `/fan`. It starts in **automatic**, following `batt_temp_hi` up a 35 → 48 °C curve, running flat out for the whole of a DC charge, and stopping above 90 km/h — ⚠️ every one of those three numbers is a considered choice rather than a measurement of this radiator, marked as such wherever it appears ([`docs/fan-control.md`](docs/fan-control.md) §4 and §8) — while the dashboard slider takes it over until the bike is switched off. ⚠️ One of the two opt-**in** switches here, `SERVICE_WRITE_ENABLED` being the other: almost no Eva has this fan, so unset means the Pi never opens `/sys/class/pwm`, never spawns `pinctrl` and answers 404 at `/fan`. Needs the `config.txt` lines in `INSTALL.md` §1 first. See [`docs/fan-control.md`](docs/fan-control.md). |
| `CAN_ENABLED` | on | `0` skips CAN altogether — coolant probes only. |
| `OBD_ENABLED` | on | `0` makes the bus **listen-only**: broadcasts are decoded, nothing is ever transmitted. Costs you the OBD-II PIDs and the trouble-code list. |
| `ELOCK_ENABLED` | on | `0` skips the one-shot keys-paired read from the E-LOCK ECU at startup. |
| `WIFI_ENABLED` | on | `0` skips the wifi poller and the diagnostic dumps it writes. The poller records what the radio is doing as `wifi_*` signals and, after two minutes of _disconnected while the hotspot is in range_, writes a full state dump to `wifi-diag/` — because the Pi can only be asked about its wifi over the wifi that is failing. See [`docs/wifi.md`](docs/wifi.md). |
| `WIFI_IFACE` | `wlan0` | Which radio the poller watches. |
| `WIFI_HOTSPOT_SSID` | **none** | ⚠️ **No default, on purpose** — this is a public repo and an SSID is a personal network identifier. Set it to the name of your phone's hotspot; it is what `wifi_hotspot_seen` and `wifi_network` are measured against. Leave it unset and the poller still records the radio's own state, says so loudly at startup, and never writes a fault dump. |
| `BLE_ENABLED` | on | `0` skips the Bluetooth link to the Connectivity Hub (torque/power, odometer, vehicle state). GPS also arrives over CAN, so you keep position either way. |
| `BLE_MAC` | discover | Pin the hub's address instead of finding it by advertised name. |
| `GPS_TIME_SYNC` | on | `0` never steps the system clock from satellite time. The Pi has no RTC, so leave it on unless you have another time source. A step needs five consecutive satellite readings that agree — see [Clock](#clock). |
| `CUSTOM_BMS_CONFIG` | unset | Set to `1` **only** if the pack's BMS has been reflashed with the custom config — see [below](#custom_bms_config--set-this-only-if-you-flashed-the-custom-config). Leave unset on a stock bike. |
| `RIDE_LOG_PUBKEY` | `./ride-log-key.public.pem` | Where the sealing key lives. |
| `RIDE_LOG_DIR` | `./ride-logs` | Where sealed `.celog` segments are written. |
| `VCU_PARAM_DIR` | `./vcu-params` | Where service mode leaves parameter snapshots for `/vcu-params` and `/vcu-backup.csv` to serve, and where the write audit journal `service-writes.jsonl` is appended. |
| `SERVICE_MODE_ENABLED` | on | `0` forbids the dashboard from starting a VCU parameter read. That read is the only thing here that puts requests on the bike's bus on purpose; the snapshot is still served and exported either way. The safety gate applies regardless — see [Service mode](#service-mode). |
| `SERVICE_WRITE_ENABLED` | **off** | `1` lets the dashboard **change** things on the bike: any of 269 calibration parameters, the service point, the bike's clock, and the stored trouble codes. ⚠️ One of the two opt-**in** switches here, `FAN_ENABLED` being the other — everything else defaults on and takes a `0` to disable — so a Pi nobody has told about it cannot write to a motorcycle's EEPROM. It is the only one of the two that can reach the bike at all. Separate from `SERVICE_MODE_ENABLED` on purpose. See [Changing something on the bike](#changing-something-on-the-bike). |

### Grafana

The whole path from a ride to a chart, on the laptop. Grafana reads a plaintext SQLite file, and the bike only ever produces sealed segments, so decrypting is a step you cannot skip:

```bash
# 1. park within wifi range and pull the sealed log off the bike
curl -O http://cool-eva.local/dl        # or just open http://cool-eva.local/dl on your phone

# 2. import it. Needs the PRIVATE key from step 6 of Setup, in the current directory.
#    Decrypts into a staging file, puts back the waypoints a rebuild would drop, builds
#    the route map's track, and only then replaces rides.db. Measured end to end at
#    3 min 55 s for 26 files / 45.9 M readings / a 2.5 GB result; it scales with the
#    archive, not with what is new, because a /dl dump contains all of it.
node --experimental-strip-types scripts/import-ride-log.ts dl --out rides.db

# 3. Grafana at http://localhost:3000 — no login, dashboards already provisioned
docker compose up -d
```

The datasource points at `/repo/rides.db` (`grafana/provisioning/datasources/sqlite.yml`), which is this repo's directory mounted into the container — so `rides.db` must sit at the repo root. Every panel says **No data** until step 2 has run at least once.

**Which files to give it.** A `/dl` download is every day file concatenated at the moment you download it, so a later import is a _rebuild from all of them_, not a top-up: pass the newest dump plus the day and boot files written after it, and nothing that the dump already contains. `reading` has no uniqueness constraint — pass a dump **and** the day files inside it and every overlapping row is stored twice, silently. ⚠️ The gap in that rule, stated because nothing closes it yet: a day file written after the dump was taken also holds the earlier part of that day, so excluding it to avoid doubling loses whatever was logged between the dump and midnight.

**What the step does, in order** (`scripts/import-ride-log.ts`, and `scripts/ride-import.ts` for the refusals):

1. **Decrypt into `rides.db.import-<runId>`** — never over the live file, which is what makes an import that fails halfway cost nothing. `--heap-mb` (default 24576) is the V8 heap the decrypt gets; a dump that outgrows it dies with a heap OOM and the step says so.
2. **Re-run the waypoint recovery.** Once over the whole archive, reported and writing nothing, so you can see what falls outside the window; then once more with `--commit` up to `2026-09-10T21:55:06Z`, the instant #197 changed the hold beat the recovery models. `--recover-from` / `--recover-to` override it. `docs/waypoints.md` §"Not losing the ride log".
3. **Materialise the route map's track** into `route_track`, which is why the map now loads in well under a second. `--materialise-only <db>` runs just this stage on a database you already have. `docs/route-map.md` §"Materialised once, not per load".
4. **Swap** — and refuse instead, leaving the staging file for you to look at, if the new database covers fewer readings or a shorter span than the one it replaces (`--allow-shrink` if you meant it), or if `rides.db-wal` is non-empty because something still has the old file open. The replaced database is kept as `rides.db.bak-replaced-<runId>`; delete it once Grafana looks right.

`scripts/decrypt-log.ts` on its own is still there and still the right tool for a scratch database (`--out evidence/scratch.db`); it refuses an existing `--out` and only `--force` appends into one.

Ten dashboards are provisioned from `grafana/dashboards/`, one file each:

- **Cooling** (`cooling.json`) — ΔT across the pack, heat removed against an assumed coolant flow, inlet/outlet/ambient, per-module temperatures, powertrain temps.
- **Battery & cell balancing** (`battery-cells.json`) — per-cell voltage and per-module temperature heatmaps, spread over time, the cell limits the BMS is actually configured with.
- **Ride summary** (`ride-summary.json`) — speed, power, torque, energy, peak temperatures, position, bike state. Torque appears twice on purpose: against power from the Connectivity Hub, and as the inverter's own commanded-vs-delivered pair off `0x02C` with the hub's reading laid over it as an independent check. See `docs/can-decode-findings.md` §0x02C for what the gap between the two means and why that panel breaks the hub's line rather than holding it.
- **Charging** (`charging.json`) — charge sessions, charger mains and DC side, the BMS system-state lanes.
- **Isolation & faults** (`isolation-faults.json`) — the BMS isolation test in raw ADC counts, the error and warning flags, the stored diagnostic code counts, the BMS IO lines.
- **Explore & data health** (`explore.json`) — every logged signal, a browser over the whole registry, and how long each signal has been quiet.
- **Charge manager** (`charge-manager.json`) — the DC fast-charge side, off CAN `0x605`/`0x610`/`0x615`/`0x620`/`0x625`: the current the vehicle requests against the three separate limits that bound it and against what the pack actually took, the state machine split back out into its factory fields, and the fault source and code. The **Charging** tab above cannot show a DC session — the onboard charger's frames are absent through one.
- **Power & battery** (`power-battery.json`) — power in kW against battery percentage, charge power derived from `dc_v × dc_a` and pack power measured, plus cell-vs-board pack temperature.
- **Route & charging map** (`route-map.json`) — where the bike went and where it charged, on a map. The track is every GPS fix in the window, coloured by speed; charge stops are pins sized by energy added and coloured by how stale their position is, because the hub sleeps while charging and a stop is drawn at the last fix from before it was plugged in. Both tables drill down into the dashboards above with the range already set. See `docs/route-map.md`.
- **Trouble codes** (`trouble-codes.json`) — every diagnostic code the bike has reported, named from Energica's own type-approval table. The code table in that file is generated; see `grafana/README.md`.

`grafana/README.md` collects the datasource and panel traps that querying log-on-change data in this plugin keeps producing — read it before writing a new dashboard.

### Clock

The Pi has no RTC. Without a network it boots with whatever date the filesystem left behind, so satellite UTC off the Connectivity Hub is the only real time source out on the road, and the service steps its own system clock to it (`date -u -s`).

Trusting a single frame to do that turned out to be expensive. A corrupted year byte reading 60 decoded as **2060**, the clock was stepped 34 years forward, and the five-minute anti-thrash cooldown then blocked the correction that would have undone it — so one bad frame cost five minutes of rows, not one row. Four such frames are in the history and two of them landed while the service could set the time: **49 772 rows in `rides.db` are stamped 2060** because of them.

What decides a step now (`src/gps/clock-gate.ts`, pure, replayed against the real frames by `scripts/check-gps-clock.ts`):

- **Five consecutive readings must agree**, each within 3 s of the others once carried forward by the **monotonic** clock. The corruption is always a single frame — the frames either side of all four are sane — so a lone bad one can never corroborate itself. Costs 1.4–5 s of a cold boot.
- **A floor, and no ceiling.** Nothing before 2026 is a real fix (that catches the GPS week-number rollover, which reads 1980 or 1999, and a zeroed date field, which reads 2000). There is deliberately **no upper bound on the calendar** — a "2024 to 2035" window would just be a fix with an expiry date. 2060 is refused because nothing agrees with it, not because 2060 is a year we disbelieve, and the check proves that by replaying every case ten years on and requiring identical verdicts.
- **Cold boot is not drift.** With no confirmed time yet, a step of many hours is expected and allowed — two real ones in the history are 20 h 46 m and 20 h 38 m. Once there _is_ a confirmed time, a candidate must also stay within 10 s of it carried forward, which is what refuses a 34-year jump mid-session. That anchor expires after 5 minutes without reconfirmation, so a session can always re-derive its time rather than being locked out.
- **The cooldown is recoverable.** It still holds off small corrections so we don't fight `systemd-timesyncd`, but a disagreement over an hour bypasses it — that is not thrashing, that is a broken clock, and waiting it out is what made one frame cost five minutes.
- **Refusing to sync is not allowed to be quiet.** Every non-step state is one the clock could in principle sit in forever, so the reason is logged on every change and repeated every 5 minutes while it persists — a window that keeps contradicting itself warns, rather than looking exactly like the two seconds of start-up that print the same line.

Satellite count deliberately is **not** part of this. It reads 9 and 10 at the corrupt frames, against a population where 41 % of all readings are below 8, so no threshold separates them; the floor of 4 in the decoder stays as a receiver sanity check. The wall clock is only one of the two clocks recorded anyway — `gps_epoch_s` is logged raw against every row's own timestamp, and every row now carries a write-order counter as well (see below), so both order and true time stay recoverable even from rows already stamped wrong.

### Encrypted ride log

A stolen bike is a stolen SD card, and the log holds every route you've ridden — including the one that ends at your front door — plus the ID of the key fob that starts it. So the Pi can be given a **public key only**: it seals every reading it writes and cannot read any of it back.

Set it up once, on the laptop:

```bash
node --experimental-strip-types scripts/generate-log-key.ts   # writes both keys
# back the PRIVATE key up (password manager) — it is the only thing that can ever read the logs
scp ride-log-key.public.pem pi@cool-eva.local:/home/pi/cool-eva/
```

The pair is generated on the laptop and never on the Pi, deliberately: the bike is supposed to hold a public key only, and a Pi that generated the pair would have had the private half on the SD card — which is exactly what the sealed log exists to make worthless. `scripts/setup-service.ts` checks for the key and prints these commands with your hostname filled in if it's missing.

Restart the service; it logs `ride-log: encrypting to …` once it finds the key. Sealed segments land in `ride-logs/*.celog`. To read them back:

```bash
# a /dl download is a single file; ride-logs/ off the Pi is a directory — both work
node --experimental-strip-types scripts/decrypt-log.ts cool-eva-2026-08-01.celog
node --experimental-strip-types scripts/decrypt-log.ts ride-logs/ --out rides.db

# the key is looked up relative to the CWD, so from anywhere else:
RIDE_LOG_PRIVATE_KEY=~/Documents/cool-eva/ride-log-key.private.pem \
  node --experimental-strip-types scripts/decrypt-log.ts ~/Downloads/cool-eva-2026-08-01.celog
```

That rebuilds an ordinary SQLite file, so Grafana and the dashboards work against it — with one exception since the route map's track was materialised: its map panel and its "GPS points mapped" tile read a `route_track` table that only the import step builds, and both show an error badge until `scripts/import-ride-log.ts --materialise-only <db>` has been run against the file. ⚠️ And a `--force` decrypt into a database that already has that table leaves it **stale** rather than absent, which looks like nothing at all — `docs/route-map.md` §"If the table is missing" has the measurement.

> ⚠️ Decrypting **refuses** an existing `--out` — delete it, choose another name, or pass `--force`, which **appends** and will happily store a second copy of everything the file already holds. Point it at a fresh file rather than at an existing archive you care about, and use `scripts/import-ride-log.ts` (§Grafana) when the archive you care about is the one being replaced. The Grafana datasource reads `/repo/rides.db`, which is why the walkthrough above uses that name. The sealed log is also **~10x smaller** than the equivalent SQLite (gzip before encryption, and crypto overhead is per 30-second segment rather than per row).

Each segment uses a fresh ephemeral X25519 key (ECDH → HKDF-SHA256 → AES-256-GCM), so compromising the Pi cannot retroactively decrypt anything already written. Segments are independently sealed, so damage is contained: the reader resyncs on the next segment and reports what it couldn't read rather than stopping. **There is deliberately no recovery path: lose the private key and every logged ride is gone forever.** That is exactly what makes the SD card worthless to a thief.

#### What this does and doesn't hide

Holds up: the readings themselves — routes, coordinates, the key-fob ID, everything in the tables above. Whoever takes the SD card, or intercepts a `/dl` download, gets ciphertext.

Does not:

- **Timing metadata leaks.** Filenames are `rides-YYYY-MM-DD.celog` — plus `rides-boot-<session>.celog` for whatever was sealed before the clock could be believed, which leaks a boot count rather than a date (`docs/ride-log-clock.md`) — and sizes scale with how much was logged. That reveals which days the bike moved and roughly for how long, without revealing where. Since the motivating worry is someone learning your habits, that's worth knowing.
- **No cross-segment integrity.** Each segment is authenticated on its own, so tampering within one is detected — but segments can be deleted or reordered without the reader noticing. It protects confidentiality, not completeness.
- **`/dl` is unauthenticated** on port 80, like the rest of the server. The payload is sealed, so the exposure is the metadata above rather than the data — but it's a wider audience than "whoever holds the SD card".

## Trouble codes

The bike keeps several completely different fault records, and the Faults tab shows them apart because merging them would be wrong — they answer different questions:

|  | What it is | How many, right now | Where from |
| --- | --- | --- | --- |
| **Active** | What the bike says is wrong _at this moment_. It flickers — one code was present on 2 of 8 consecutive polls at a standstill | 0-1 | Connectivity-Hub message type 25, over Bluetooth and on CAN `0x410`, which the instrument cluster transmits |
| **Stored** | Everything that has _ever_ been wrong and not been cleared. It only climbs | **39** | OBD-II **mode 03**, over ISO-TP |
| **Pending / permanent** | Would be OBD-II modes 07 and 0A | — | **no response.** See below |
| **Freeze frames** | The conditions the bike recorded _at the moment_ one specific code latched | not read yet | KWP `0x17` on the A8 micro. Decoder, tables and transport are in, and the wire format is verified against 29 captured replies. See [Freeze frames](#freeze-frames) |
| **Freeze-frame log** | The whole stored history of the above, **with timestamps** | not read yet | KWP `0x35`/`0x36`/`0x37` bulk upload on A8 — the factory tool pulled 1198 records in one ~7-minute transfer. See [The multi-frame transport](#the-multi-frame-transport) |

Mode 03's reply is 80 bytes, so it needs ISO-TP: a First Frame, a flow-control frame back from us, then eleven Consecutive Frames. `src/can/iso-tp.ts` reassembles it and `src/diagnostics/obd-dtc.ts` decodes it — both pure, bytes in and codes out, so a captured transfer replays on a laptop:

```bash
node --experimental-strip-types scripts/decode-dtc-response.ts
# → replays a real 2026-08-04 transfer and checks it still decodes to the same 39 codes
```

Codes are named from Energica's own type-approval table, reconciled against the manufacturer's service-tool copy of it (`src/diagnostics/dtc-table.ts`, 154 codes). All 39 of this bike's are in it. **Mode 01 PID 02** — the freeze-frame code, i.e. the one the bike captured when it lit the lamp — reads `P0514`, _"Error reading temperature"_, which is why the warning light is on.

**Modes 07 and 0A return nothing at all** — silence, not a refusal, across six attempts. That means "not implemented" and "implemented but withheld" cannot be told apart from here, so the dashboard says **"no response"** rather than "none pending". Those are different claims and only one of them is true.

The transfer is not reliable — the First Frame arrives every time and the Consecutive Frames sometimes never do, at somewhere between 25 % and 70 % per attempt. It is retried, and it is read once a minute from inside the sequential OBD poll loop so nothing else of ours is on the bus while it runs.

### Freeze frames

A stored code says _what_ went wrong. A freeze frame says what the bike was **doing at the moment it latched** — pack voltage, motor speed, air temperature, and for a water-pump code the measured pump current itself. It is a different service on a different bus from either list above: KWP **`0x17`** with a component number, on the **A8** safety micro, after a `10 81` session.

What makes a freeze frame readable rather than a hex dump is Energica's own data, and both halves are now in this repo:

- **`src/diagnostics/infokey-table.ts`** — the 120 telemetry fields the manufacturer's service tool calls _info keys_, each with a name, a unit, a C datatype and a scaling equation. Transcribed from two independent copies of Energica's own table, which agree on all 120 rows.
- **`src/diagnostics/fault-infokeys.ts`** — **944 curated references** across 155 faults saying which of those fields to show for each code, _in order_. That order is the payload's byte layout, not a display preference.

Tap any stored code on the Faults tab and it opens to show that shortlist: Energica's own answer to "what should I go and measure for this fault". That part needs no bus at all — it is served from `/fault-infokeys`, static and cached.

```bash
node --experimental-strip-types scripts/check-freeze-frame.ts
# → checks the 120 fields and 155 shortlists against dtc-table.ts, then replays
#   31 freeze-frame transfers (29 captured, 2 constructed) through the real
#   reassembler and decoder
```

> ✅ **The wire format is verified.** The _request_ was always proven twice over — the factory tool sent `0x17` to A8 29 times in a 2026-08-08 capture and got 29 positive replies, and Energica's own code builds exactly that frame. This box used to add that the _response layout_ "has never been captured" and that the record-count byte was "genuinely open". Both were wrong: the 29 replies were on `7E0` all along, and the search that missed them looked at `7C0`, which carries only requests. They are committed in `scripts/captured-freeze-frames.ts`, `recordCount` is 1 on all 29 and asserted, and the header is 5 bytes — settled by decoding all 29 against physical bounds, since the lengths alone cannot separate a 5-byte header with a trailer from a 6-byte header without one. One byte per reply is still undecoded. See [§5.1 and §11.3.1](docs/diagnostics-and-checks.md).

### The multi-frame transport

Every freeze frame is multi-frame — the header alone is 5 bytes and an extended-addressed single frame holds 6 — so reading one means **transmitting between the request and the rest of the reply**. `src/vcu/kwp-client.ts` was built never to do that. It now can, and the property that made the old rule worth having is intact: the flow-control frame is addressed to the target the **caller** named, never to an address read off the bus.

> ⚠️ **Ordinary parameter reads go through this transport too, since 2026-09-14.** A bank-1 record was assumed to be 1 or 2 bytes because that is all `params.ecf` describes — but A8 answered index 278 with a 7-byte reply, and #219 types 278, 279 and 626 as 4-byte DWORD from the firmware's own table. Not one request byte changed (a 3-byte `22 <hi> <lo>` segments to exactly the Single Frame that was sent before, padding included); what changed is that a reply too wide for one frame is now assembled instead of reported. [`docs/vcu-parameters.md` §9](docs/vcu-parameters.md#9-the-read-path-read-only-by-construction).

|  |  |
| --- | --- |
| **`src/vcu/multiframe-codec.ts`** | Pure. A closed union of the five multi-frame **reads** — `0x17` freeze frame, `0x18` DTC list, `0x35`/`0x36`/`0x37` upload — with a throwing default and an allowlist re-check on the emitted service byte. No raw-bytes entry point, nowhere to put a value. Plus ISO-TP segmentation and flow control for extended addressing. |
| **`src/vcu/multiframe-transfer.ts`** | One exchange over the bus: answers a First Frame with `<target> 30 FF 00` **synchronously from the frame handler** (delaying it measurably cost transfers on the OBD channel), segments a request that does not fit one frame, and bounds a stuck responder with a frame cap, a payload cap and per-stage timeouts. |
| **`src/vcu/freeze-frame-log.ts`** | The bulk read: `0x35`, then N × `0x36`, then `0x37`. Takes a bus lease, paces itself, yields between blocks, is cancellable mid-transfer, and sends the closing `0x37` on every path out — including a cancel. |

A reply that **under-fills** is abandoned, never completed at its declared length. That is the specific failure this is built around: a short Consecutive Frame mid-transfer leaves the sequence numbers running 0, 1, 2…, so nothing looks wrong, and taking what arrived shifts every later field into numbers that still have units on them. `scripts/check-kwp-multiframe.ts` asserts it, along with the gapped, oversized, foreign and flooding replies.

```bash
node --experimental-strip-types scripts/check-kwp-multiframe.ts   # no bike
```

Reading it off the actual bike is `scripts/read-freeze-frame.ts`, and that script is **the only way to run this** — a First Frame has to be answered within milliseconds, which is not something you can type into `cansend` in time. Stop the service first and bring `can0` up ACTIVE yourself; the script's header has the exact commands and the reason it does not do it for you.

```bash
node --experimental-strip-types scripts/read-freeze-frame.ts --list           # 0x18: which components have a code
node --experimental-strip-types scripts/read-freeze-frame.ts --component 44   # 0x17: one freeze frame
node --experimental-strip-types scripts/read-freeze-frame.ts --log            # the whole stored log, minutes
```

Every reply is printed as **raw hex first**, before any decode. That is the point of the run: the BULK LOG reply layout (`0x35`/`0x36`/`0x37`) is still unverified — `0x17` and `0x18` are now both captured and confirmed, so the bytes are the result and the decode is a hypothesis printed beside them.

> ⚠️ **For the bulk log, the request side is proven and the reply side is not.** (`0x17` and `0x18` are settled — see above and §11.3.1. This box is about `0x35`/`0x36`/`0x37`.) The check asserts that this repo's segmenter reproduces `A8 10 0C 35 12 FF FF FF` — a frame captured off this bike — byte for byte, and that the `0x18` request matches the one recovered from the manufacturer's code. This box used to say that **no multi-frame reply and no flow-control frame had ever been captured on this channel**, in either direction. That is no longer true, and was already false when written: the 2026-08-08 capture holds 1229 First Frames and 43 786 Consecutive Frames on `7E0`, plus 1229 flow-control frames on `7C0`. Twenty-eight of those replies are committed in `scripts/captured-freeze-frames.ts` and replayed through the production reassembler. The one reply replayed with real bytes behind it is A8's bank-2 identifier `0x2001`, reconstructed from two independent live records that had to agree and did. Everything else is constructed from the documented framing.
>
> Three things are outright guesses, each marked at its definition: **seven of the ten operand bytes** after `35 12` (only `FF FF FF` was captured, in the First Frame), whether `0x36` carries a block-sequence counter, and whether the micro sends a flow control before our request's Consecutive Frames. All three are settleable **offline**, from `capture-20260808-182129-600daf87.log` on the Pi — the census that produced these notes filtered by service byte, and a Consecutive Frame has none, so the bytes are still in that file.

## VCU parameters, by name

The VCU's calibration EEPROM — throttle maps, cell limits, current thresholds, the charge-current ceilings — is readable off the bus **by name, with no authentication**. The two micros serve it as KWP bank 1, and the mapping is simply `CommonIdentifier = 0x1000 | index`, where the index is the row number in Energica's own `params.ecf` parameter file. Parameter _n_ is `22 [0x10|hi] [lo]`.

`src/vcu/param-file.ts` carries a copy of that file — 277 names, widths and micro assignments — so nothing depends on a path in one person's iCloud folder. **Its values are another bike's**: the file came from a different variant, and 21 of the 233 parameters the A9 serves read differently here (`MAX_DC_CHG_CURRENT` is 75 A on this bike against the file's 60). It is a name table, and the column showing its values is labelled as another bike's everywhere it appears.

**Which names are right depends on which of Energica's parameter tables your bike runs — and the bike will tell you.** `TABLE_TYPE = (family << 12) | revision`, and the VCU reports its own at parameter 276 `TABLE_TYPE_uC` (A9) and 277 `TABLE_TYPE_uS` (A8). This Ribelle reads `0x4017` = table **16407**; `params.ecf` is one revision older, **16406**.

**All 28 tables Energica's 2024 service tool can select are shipped**, in `src/vcu/table-catalog.data.ts`, and the one matching what your bike reports is what the names come from. That is the difference between this working on one motorcycle and working on yours. How much it matters depends on which table you are on:

| your table | ids this software would have got wrong under one hardcoded 16407 |
| --- | --- |
| 4118 / 16406 | 1 (id 249, `LM_TYPE` vs `R_BRAKE_POPUP`) |
| 20503 | 2 (`POSLIGHTS_*` vs `FPOSLIGHTS_*`) |
| 20502 | 3 |
| 24598 | 6 (`NT_SPD_*`/`NT_TRQ_*` vs `DBW_DUMMY_WORD13..17`) |
| **any of the 20 `RegenFade` tables** | **25** — ids 70–94 are `RegenFade_0..24`, not the battery cell block |

That last row is the one that matters. On 20 of the 28 tables, ids 70–94 are a 25-point regen fade curve; on the other 8 the same ids are `CELL_COUNT`, `CELL_OVERVOLTAGE`, `CELL_TARGET_AC`, `CELLV_KA` and the rest of the battery cell configuration. **Another Energica tool in circulation writes a regen curve into the cell block today**, because it carries one table and never asks. Routing (`id → micro`) and record width (`id → datatype`) are identical across all 28, so nothing on the wire can notice: the write is correctly framed, lands on the right micro, is accepted, and reads back exactly as sent.

So every sweep reads its own table type back, says so in the journal and at the top of `/params.html`, and **re-names the whole snapshot from the table the bike named** before storing it. A bike naming a table this software does not carry gets shouted about rather than silently mislabelled — and the message says how to add it, because that is a thing you can do yourself.

### Adding your bike's VCU parameter table

If your VCU reports a `TABLE_TYPE` that is not in the 28 (Energica has shipped more since; another owner reports a build with about five more, one of them for a Corsa), the tool refuses to write anything and tells you this. Fixing it takes one command and no reverse engineering:

```bash
# 1. find the main executable of your own Energica service-tool install — the dealer
#    diagnostic application itself, not its installer. On Windows it lands under
#    C:\Program Files (x86)\Energica\, in the tool's own subdirectory, where it is by
#    far the largest file (~137 MB in the 2024 build). Copy it anywhere; the script
#    only reads it.
# 2. regenerate the catalogue from it (works on macOS/Linux/Windows — no .NET tooling,
#    and nothing has to be installed on the machine you run it on, just the file)
node --experimental-strip-types scripts/extract-vcu-tables.ts /path/to/service-tool.exe

# 3. tidy and check
npx prettier --write src/vcu/table-catalog.data.ts
npm test

# 4. `git diff src/vcu/table-catalog.data.ts` shows exactly which tables are new and
#    which ids they rename. Send it as a PR — every Energica owner after you gets it.
```

**It merges, it does not overwrite.** Energica builds do not all carry the same tables — the 2021 build has 18 where the 2024 one has 28, and the ten it lacks include every table with the battery cell block — so running it against an older install adds what yours has and keeps what the repo already had. A `TABLE_TYPE` present in both with _different_ content stops the script rather than picking a side: every table shared between the two builds seen so far is byte-identical, export stamp included, so a conflict is a finding worth an issue.

The tables are ZIP archives stored as .NET resources inside the exe, and the **resource name is the answer**: `_16407` is the table a VCU reporting 16407 runs. That name is the only thing in the binary binding a table to the number your bike reports, which is why the script walks the resource directory rather than scanning the file for ZIPs — a scan finds more archives (each is stored twice, and four have no `TABLE_TYPE` name at all, so the service tool itself can never select them) and throws the binding away.

Each table is stored as a **delta against `params.ecf`** — the ids whose name or signedness differ — because `id → micro` and `id → datatype` never vary. All 28 come to ~46 KB of source that way, against ~1.1 MB as standalone tables, which matters on a Pi Zero. Each carries a fingerprint taken from Energica's own bundle, and rebuilding a table checks against it, so a delta that has drifted from the `params.ecf` text underneath it is a loud failure rather than a subtly wrong name table.

Two things Energica's bundles do **not** contain: any values (`vehicleValue` is null in all 28) and the `[SECTION]` groupings. Both come from `params.ecf`, which is a 16406 bike's — so they travel only as far as the name does. An id another table renames loses both, because "the other bike's `CELL_COUNT` is 80" is not a fact about `RegenFade_0`.

### Service mode

Reading them is a thing you **do**, from the phone: **Menu → Service mode → `🔧 Read VCU parameters from the bike`** (two taps — the first arms it). Live progress, `⏹ Stop`, and then `⬇ Export N parameters as vcu_backup.csv`, which is byte-compatible with another owner's `energica_tool.py`.

**It only starts with the bike proved parked**, and it stops by itself if that stops being true. `src/vcu/service-gate.ts` requires road speed zero on CAN `0x104`, the motor at zero rpm, the VCU's own `moving` bit clear, and `go` / `go_request` / `throttle_on` clear — every one of them fresh, from 100 Hz broadcasts. OBD PID `0D` corroborates the speed when it is answering. Anything stale, missing or contradictory refuses: the gate fails closed, so a bus that has gone quiet reads as "I cannot tell", never as "it is fine". The same check runs again before **every single request** the sweep sends, and a watchdog re-runs it five times a second, so riding away ends the read rather than racing it.

**Stationary and charging is allowed**, deliberately — you cannot test a DC charge-current limit on a bike that is not plugged in. Three things can witness the charge: the DC fast-charge contactor (`0x102` b3 bit 0), the onboard AC charger's frames (`0x305`/`0x306`, which do not exist on DC), and a settled `charge_manager_state` (`0x610` b7, which covers both) — and any of them being fresh lets `energized` be set, because a charging bike's HV side is up by definition. ⚠️ The charge manager reporting an EMPTY INLET cancels all three: a failed attempt on 2026-08-09 broadcast the settled AC value for 14.8 s with nothing in the inlet. `speed_can_kmh`/`motor_rpm_can` may also be absent while charging, though the reason given for that rule is refuted (#194). Nothing else relaxes — the `0x102` bits must still be live and clear, and a fresh speed reading that says the wheel is turning still refuses.

### Probing one identifier

The sweep covers the 277 parameters the bike's own table describes, plus the 25 more A8's own firmware table serves that `params.ecf` does not name — 302 identifiers, bank 1, on the two VCU micros. Those 25 (the odometer master, the last-service stamp and 18 with nothing traced) are shown unnamed, with raw bytes and no typed value, because their width comes from a firmware image and their signedness from nowhere at all: [`docs/vcu-parameters.md`](docs/vcu-parameters.md) §2. The **`/vcu-probe` endpoint** reaches anything else — name the micro, the bank and the index and it reads that one: `curl -X POST -H 'X-Cool-Eva: service-mode' '<pi>/vcu-probe?target=A9&bank=2&index=258'`. It had a panel on the service sheet until 2026-08; that was removed as clutter for something done a handful of times ever, and what it was for is recorded on issue #51. What lives out there and nothing here could reach before: **bank 2 is live data** rather than stored settings. Same header, same gate and same single-flight as a sweep.

> ⚠️ This briefly offered a **charge manager** target, on CAN `0x7C3`/`0x7E3`. That pair is wrong and has been removed: **`0x7E3` is the dashboard's request id**, so the option could have questioned the dashboard while the page said otherwise, and `RequestFrameIDs.CHM = 0x7C3` turns out to be a dead enum the manufacturer's own code references nowhere. Node `0xA4` is the charge manager's real 11-bit identity, but the ECU actually answers on **29-bit ISO-TP** — request `0x18DA09F1`, response `0x18DAF109` — which needs `ext: true`, its own RX filter and its own addressing math. That is a feature rather than a constant, so the target is gone rather than re-pointed; the full note is in `docs/vcu-parameters.md`, "The charge manager was a target here, and it was WRONG". Whoever adds it should know it is **off-bus when parked** (it answers only during a live charging session), that identification reads need no SecurityAccess, and that its deeper access uses a CRC-16/CCITT algorithm that is **not** the VCU's bit-swap.

**It is on demand, never automatic.** These are configuration: they do not move while riding, so logging them as time series would spend SD-card writes re-recording constants, and 277 more keys in the WebSocket snapshot would cost every dashboard update. Nothing starts a sweep at boot, on a timer or per page load. What is worth knowing is that one _changed_ — so every run diffs against the previous snapshot and says so loudly in the journal. `GET /vcu-params` and `/params.html` serve that snapshot from disk and **never touch the bus**.

A sweep survives being interrupted: each row is appended to `vcu-params/sweep.partial.jsonl` as it arrives, and starting another one resumes from there rather than beginning again — so a stop, a gate exit or a `systemctl restart` costs only the parameters not yet read. Snapshots are gitignored — they are one motorcycle's — while the name table needed to take your own is committed.

```bash
node --experimental-strip-types scripts/check-vcu-params.ts   # on a laptop, no bike:
                                                              # codec, all 28 name tables, backup CSV,
                                                              # the safety gate, and the whole write path
```

### Changing something on the bike

> ⚠️ **Nothing in this section has ever been transmitted by this repo** (as of 2026-08-16 — the bike is away for about a week). The write _service_, its framing and its authentication rule are proven: `obd-garage/DIAG_ADDRESSES.md` §9 is a passive capture of **Energica's own diagnostic software** writing to this bike's A8, and `obd-garage/VCU_PARAM_CHANGES.md` records five parameters written to this bike with a scratch tool on 2026-08-09, surviving a power cycle. What has not been exercised is _this code_. Treat every claim below as reasoning until a real bike answers.

Writing is **off unless you ask for it**: `SERVICE_WRITE_ENABLED=1`. It is one of the two switches here that default to off — `FAN_ENABLED` is the other, and it drives an accessory off the Pi's own GPIO rather than anything on the bike — and it is separate from `SERVICE_MODE_ENABLED` on purpose: reads and writes are not the same risk and must not share an off button.

Every parameter in the bike's table may be written — **269** of the 277, the other eight being four names that appear twice and so have no unambiguous address. ⚠️ This was a closed allowlist of five until 2026-08-21; the argument for it was that an index two away from the five is `CELL_OVERVOLTAGE`, and that argument was about INDEX typos on an interface that only ever took a name.

What the five below still have is **research** — measured bounds and a warning written by someone who went and looked. The other 264 carry the datatype's full range and say, on screen, that nothing here knows what they do. Two guards do the work absence used to: every write is a compare-and-swap against a fresh read, and `writeTargetProblemIn` refuses any parameter the bike's own table puts at a different index (26 of the 28 carried tables disagree about at least one of the 269). The five, with their researched ranges:

| parameter | reads | may be set to | why it is on the list |
| --- | --- | --- | --- |
| `MAX_DC_CHG_CURRENT` (258) | 75 A | 0…80 | Energica's own 60/75/80 A options write **this byte and nothing else**, so 80 is a value the factory shipped. |
| `FCHG_CURRENT_GAIN` (259) | 225 | 0…512 | ⚠️ Meaning genuinely unknown — see below. |
| `TORQUE_LIMIT` (48) | 230.0 Nm | 0…276.0 Nm | 0.1 Nm per count. The ceiling is +20 %, this repo's policy, not a measured limit. |
| `REGEN_TORQUE_LIMIT` (49) | 60.0 Nm | 0…90.0 Nm | Likely clipping against `REGEN_CURRENT_LIMIT` (120 A) anyway. |
| `VSM_CONFIG_1` (16) | `0x1113` | **one bit only** | Heated handlebars, mask `0x0004`. |

⚠️ **And the bike has to have said which parameter table it runs, or nothing on that list may be written at all.** A parameter is written **by index**, and what an index _means_ comes from the table — but routing (`id → micro`) and record width (`id → datatype`) are identical across all 28 of Energica's tables, so a write under the wrong table goes to the right micro with the right number of bytes, is accepted, reads back cleanly, and has changed a **different parameter**. There is no NRC, no reply shape and no read-back anywhere in that sequence that can report it. 151 of 278 ids carry a different name in at least one other table, and id 249 (`LM_TYPE` in 16406, `R_BRAKE_POPUP` in 16407) is one that was found rather than imagined.

So `src/vcu/table-gate.ts` refuses a parameter write unless **both** micros have named the **same** table and it is one this software carries. The question it asks is "do we have your table?", not "are you this particular motorcycle" — all 28 pass. The ways it can fail are reported differently, because the remedies do not overlap:

| state | what it means | what fixes it |
| --- | --- | --- |
| `confirmed` | 276 and 277 both named a carried table, and the allowlist means the same thing on it | — writes are allowed |
| `mismatched` | a micro named a table this software does not carry | **no read helps** — but you can fix it: [add your table](#adding-your-bikes-vcu-parameter-table) |
| `split` | the two micros named **different** tables. Separate EEPROMs, possibly flashed at different times | **no read helps.** Nothing here holds one table per micro; picking one would name half the ids wrongly. Please open an issue with both numbers |
| `unwritable` | the table is carried, and one of the five RESEARCHED parameters is not called that on it (the other 264 are checked per write instead, by `writeTargetProblemIn`) | `src/vcu/write-targets.ts` needs an entry correct for that table. (No shipped table does this — all 28 agree on ids 16, 48, 49, 258 and 259) |
| `unusable` | a micro answered with a record the width column forbids, so it named nothing | the framing of that whole sweep is in question |
| `unread` | one or both micros have never been asked | **a sweep.** The refusal names the read: parameter 277 `TABLE_TYPE_uS` on the A8, `22 11 15`, read-only, no SecurityAccess |

> ⚠️ **This bike is in the `unread` state today (2026-08-18), so the gate is shut.** The A9's copy (276) was read on 2026-06-14 and says 16407; the A8's copy (277) has never been read by anyone — and id 249, the one id where the two candidate tables disagree, is an A8 parameter. The two micros hold separate EEPROMs, so one answering is not confirmation of the other.
>
> ⚠️ **Seeing the answer and recording it are different acts.** The gate reads the last **sweep's** snapshot (`vcu-params/latest.json`, written in exactly one place: the end of a sweep). A one-identifier probe (`/vcu-probe`) performs precisely this read and returns it in an HTTP response that nothing persists — so it is the one-frame way to find out what the bike says, and it cannot open the gate on its own. Run the parameter read and let it finish. The A8 is swept second and 277 is the highest index in the table, so it is the very last thing a sweep asks about — a run the safety gate cuts short is exactly the run that misses it.

The gate applies to the **two parameter actions and nothing else**. The service actions below are deliberately exempt: `31 FC` takes a routine local identifier that appears in none of the 28 parameter tables (it comes from the service tool's shared library), Mode 04 and the `0x120` clock broadcast carry no identifier at all, and the service stamp reads ids 1000-1003, outside `params.ecf` entirely. Gating them would be a refusal resting on evidence with no bearing on the action — and reads stay ungated for the reason that matters most: the way out of `unread` **is** a read.

A name that is not a parameter, or one of the four duplicated names, is rejected **in the pure codec**, not in the UI — `planWrite("NOT_A_PARAMETER_AT_ALL", …)` returns a refusal, and so does any plan whose index does not match its name, or whose index means something else on the bike's own table. `CELL_OVERVOLTAGE` now plans; what stops a careless write is the warning and the table check, not absence. And `src/vcu/write-codec.ts` re-derives the plan from the allowlist immediately before building the frame, so a plan assembled by hand or arriving over HTTP cannot become bytes. The table gate is enforced in the same place and on the same terms: `buildWriteFrame` re-judges the table-type report from the **raw words the bike sent**, never from the report's own `confirmed` flag, so forging one is useless — you would have to claim the bike answered `0x4017`, and if it did then the write was correct. `VSM_CONFIG_1` is offered as a **bit toggle and never as a word**: the same word carries the PSU type (`0x0760`) and the Bluetooth variant (`0x3000`), and a fat-fingered word write would reconfigure both. The new word is computed from the one the bike currently holds, and the pure layer asserts that only the one mask moved.

Every write is a **compare-and-swap with a read-back**:

```
10 81   open a session          22 CID   read what it holds NOW  →  refuse if it is not what you were shown
27 01 / 27 02   unlock          2E CID   write                   ←  must follow the unlock within ~2 s
                                22 CID   READ IT BACK            →  a mismatch is reported, loudly
```

The `2E` positive reply never carries the written value, so "the micro accepted it" is not the same claim as "the cell holds it" — and another owner's tool has a message for exactly that gap. Nothing here reports success without a read-back. Every attempt, **including the refused ones**, is appended to `vcu-params/service-writes.jsonl` with the before and after values.

⚠️ **SecurityAccess is the scarce resource.** About three bad attempts lock the micro until the bike is power-cycled, and asking an _already-unlocked_ micro for a seed also counts as a bad attempt — so a four-second cooldown sits between authenticated operations. The seed→key algorithm is checked against **four real seed/key pairs captured off this bike's own bus**, which is the only live ground truth in the whole write path.

**The four service actions**, in the same section:

- **Read the last-service stamp** — A8 bank 1, ids 1000-1003, a 32-bit count of seconds since 2000-01-01 UTC plus a 32-bit odometer. Read-only. **First read 2026-09-08: all four answered zero**, so the block is there and no service point has ever been set on this bike ([`docs/service-stamp.md`](docs/service-stamp.md)). They sit outside `params.ecf`'s 1…277, so no name table describes them — a sweep does now read them, since #219 — and they are deliberately **not** logged as signals — reading them costs a KWP session, and they move about once a year.
- **"Service was performed now"** — `31 FC` on A8, after SecurityAccess. ⚠️ **Irreversible**, and it takes no parameters: the firmware stamps its _own_ clock and odometer, so read the stamp and fix the bike's clock first. The routine id is **not user-enterable anywhere** — the codec takes a _name_ from a one-member union, so `31 FB` (which wipes battery statistics) has no way to be expressed. The positive response `71 FC` is inferred rather than logged, so an unexpected reply is reported as _outcome unknown_, never as success.
- **Sync the bike's clock** — one raw broadcast on CAN `0x120`: `94 FF` plus five bit-packed bytes of **UTC**. Not a diagnostic service at all, and there is no session, no authentication and no reply. The packing is checked against two frames that really went out on 2026-08-16. ⚠️ **This Pi's clock has to earn it**: the sync is refused unless satellite time has arrived recently and agrees, and unless the clock falls in a plausible absolute window — a GPS date-decode bug once stamped 49 772 rows of this bike's log as the year 2060. The confirmation asks _"Is it &lt;date and time&gt;?"_ and the Pi re-checks that the confirmed minute has not passed. There is **no way to read the bike's clock back**, so this is the one action nothing can verify.
- **Clear stored trouble codes** — OBD Mode 04. ⚠️ **Irreversible**, and the first thing in this project that changes ECU state outside the parameter table. This bike's stored list has been accumulating since before anyone started looking; the freeze frame goes with it.

The UI makes an accidental write hard in four ways: you cannot write until something has **read the value off this bike** (it becomes the compare-and-swap precondition), the confirmation **spells out old → new**, it takes **two taps** and _any_ change to the form disarms it, and the irreversible actions sit in their own block with their own arming.

That first one accepts the **last sweep's** reading as well as a fresh one, and says which it is showing and how old it is. A completed sweep has already read all 277 parameters and written them down; demanding a per-parameter read on top of that produced a form saying "not read yet" to somebody who had just read everything, and the reading was never the property that mattered — the Pi re-reads the parameter _during_ the write and refuses if the bike disagrees with what you were shown, so an older number is a likelier refusal rather than a weaker check. The read button stays, as the way to ask whether that value is still true. On top of those, an unconfirmed parameter table disables the write button outright and says which _kind_ of blocked it is — amber and "blocked until a sweep has recorded the A8's `TABLE_TYPE` (277)" when a read would clear it, red and "this bike's parameter table is not one this software can write against" when nothing on the bus will help. The page branches on the server's `noReadWillHelp`, not on the state name, so a state added later cannot quietly start rendering as "nobody has asked yet" with an instruction that leads nowhere. Both are shown whether or not the vehicle-state gate is also closed, so a trip out to the bike learns about both at once. The read button and the service actions stay live throughout, on purpose.

Each parameter carries three kinds of prose and they are shown at the three moments they are read at: **what it is** always, above the value; **why you might not want to** behind one amber toggle that counts them, because four stacked warning paragraphs above the input is how a phone in a garage becomes unusable and how warnings stop being read at all; and **how to check the bike afterwards** — `MAX_DC_CHG_CURRENT`'s free `0x625` b2 check, the key-cycle that config words need — next to the outcome _after_ the write, where it is an instruction rather than a fourth thing to scroll past.

⚠️ **`FCHG_CURRENT_GAIN` deserves its own warning.** Its direction of effect is unknown, and this is a real 50/50 rather than a gap someone forgot to close. If it is a _measurement calibration_ — which the name argues for — then raising 225 → 255 makes the bike believe it is drawing ~13 % more than it is, and it would back off **sooner**, not later. It might instead be a gain in the charge PID loop, in which case it changes loop dynamics and can oscillate. The arithmetic that produced 255 in the first place (`75 × 225/255 = 66.18 A`) has since been **retracted**: the wire request was measured at 75 while 66.2 A flowed, and 73.2 A was delivered on another day with no parameter change. Change one thing per charge session.

## Notes

- The CAN bus is **read-only unless you switch writing on**. Everything that runs by itself — passive broadcast decode, the OBD-II poller, the trouble-code reads, the KWP `0x22` parameter reads — cannot change anything in an ECU, and is built so it cannot express one: `src/vcu/param-codec.ts`'s request union has three members and nowhere to put a value, and `src/can/obd-dtc.ts` can emit only modes `03`, `07` and `0A`. That is unchanged and is meant to stay that way. The writes live behind `SERVICE_WRITE_ENABLED`, which is **off by default** — see [Changing something on the bike](#changing-something-on-the-bike). `0x11` ECUReset, `0x2F` InputOutputControl (the factory tool's actuator-test channel), `0x3B` and `0x3D` are implemented **nowhere**, and should stay that way.
- `src/diagnostics/freeze-frame.ts` is built the same way for its own service: a closed one-member request union that can encode `0x17` and nothing else. So the freeze-frame **erase** that sits beside it in the factory tool — `31 FE` with a fixed 8-byte operand and its own SecurityAccess, which wipes the bike's record of _why_ it faulted — is unreachable rather than merely unused, and it stays outside `SERVICE_WRITE_ENABLED` rather than being one more thing that switch turns on.
- Coolant history predating the CAN integration is preserved (migrated into the current schema; the original table is kept as a backup).
- Any `temperatures.db` left on the Pi from before the encrypted log is **plaintext history** — copy it off and delete it from the bike, or the SD card still gives up every route you rode before the switch.
- The one thing that _does_ write to the bike is the Bluetooth handshake: enrolling with the Connectivity Hub claims its single authorised-device slot, and after several unanswered attempts the client also tries the hub's own address. If the bike is already paired to something else, that pairing can be replaced, and the way back is clearing the stored device from the bike's own dashboard. `BLE_ENABLED=0` avoids the whole question.

## Licence

AGPL-3.0 — see [`LICENSE`](LICENSE). It reverse-engineers a vehicle you own and talks to safety-relevant hardware; there is no warranty of any kind, and what you plug into your own motorcycle is your responsibility.

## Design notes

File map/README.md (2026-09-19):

# `map/` — a fast ride map for `rides.db`

A laptop-side viewer for the decrypted ride log: the whole archive's track, the charge stops,
the waypoints and a ride list, drawn with MapLibre. It replaces the Grafana route-map dashboard
for looking at where the bike went, and it exists because that dashboard takes 12.3 s to a
painted map while ~85 % of the wait is Grafana's own pipeline rather than the database.

```bash
npm run map          # from the repo root: installs this package, then starts it
```

Then open the URL it prints. ⚠️ Vite listens on **IPv6 loopback only** — `localhost` works,
`127.0.0.1` is refused.

- **`RIDES_DB`** overrides the database path, which defaults to `rides.db` at the repo root.
  Needed when running from a git worktree, where the real archive is in the main checkout.
- **`rides.db.mapcache`** appears beside the database: the rides / charges / waypoints snapshot,
  keyed on the file's inode, size, mtime and a hash of the queries. Building it takes ~23 s on
  the real archive; after that it loads in ~4 ms. Delete it and it rebuilds. It is gitignored by
  the root `.gitignore`'s `rides.db*`.
- **The database is opened read-only** (`query_only`), and nothing here ever writes to it.
- **Tiles need internet.** The basemap is OpenFreeMap's public instance; offline, everything but
  the basemap still works. An offline PMTiles extract is phase 2 of #296.

`npm run lint`, `npm run check` and `npm run build` are what CI runs (`.github/workflows/map.yml`).
This is its own npm package with its own lockfile and is deliberately **not** an npm workspace,
so none of it reaches the root lockfile the Pi installs from.

**Every measurement behind this, and the defects found building it, are in
[`docs/ride-map.md`](../docs/ride-map.md).** Read that before changing the track pipeline.

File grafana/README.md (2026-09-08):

# Grafana dashboards

Provisioned from `grafana/dashboards/*.json` against the `frser-sqlite-datasource` plugin (uid `cool-eva-sqlite`), reading `rides.db` decrypted from a `/dl` download. `docker compose up -d` brings the whole thing up.

Everything below cost at least one debugging round. None of it is in the plugin's documentation.

## The datasource

**`rawQueryText` is the query. `queryText` is not.** The plugin does `queryText = templateSrv.replace(rawQueryText, scopedVars)` at query time, so a `queryText` written into the JSON is overwritten and never runs. Edit `rawQueryText`; if both are present, keep them identical so the file does not lie about what executes.

**Time columns must be in seconds**, and must be listed in `timeColumns`. Handing the plugin raw millisecond `ts` does not error — it silently decodes to the year 1854. Divide by 1000.0 in the query.

**Rows must be globally sorted by time.** `ORDER BY metric, time` fails the whole query with `not sorted in ascending order by time`. Sort by time alone and let the `metric` column split the series.

**`queryType` decides the frame shape, and therefore what field overrides can match.**

- `"queryType": "table"` returns the columns under their SQL aliases. Overrides match those names directly and nothing else is needed. Use it whenever the query already names its own columns — every stat tile, and the state timelines that widen the flags into one column per bit.
- `"queryType": "time series"` splits the rows into one series per `metric` value, and every series arrives in a field literally called `value` with the series name in a `metric` **label**, not in the field name. Legends read `value iso_test_1`, and an override written against the series name matches nothing, because no field is called that.

The fix for the second case is one line in `fieldConfig.defaults`:

```json
"displayName": "${__field.labels.metric}"
```

That makes the computed display name the bare metric, and overrides match it from then on — `byName` against the metric and `byRegexp` against it both work. Without it neither does, whichever matcher you pick. So the rule is not "avoid `byName`"; it is **set `displayName` on every `time series` panel**, and choose the matcher afterwards on taste.

The corollary is worth checking when you inherit a dashboard: a `time series` panel with overrides and no `defaults.displayName` has overrides that do nothing at all. The symptom is a legend reading `value coolant_in` and palette colours where named ones were configured.

**Interpolate textbox variables through `CAST(${var:sqlstring} AS REAL)`,** not `${var}` bare. A cleared textbox interpolates to nothing and turns the expression into a syntax error; `CAST('' AS REAL)` is `0.0`, which is visibly wrong on screen instead of an error card. It also stops a crafted `?var-…=` link from putting arbitrary SQL into the query, which matters because `docker-compose.yml` runs Grafana anonymous-admin against a read-write mount.

## Panels

**State timelines ignore value mappings on numeric fields.** They label each region with its threshold bucket instead (`-∞+`, or `< 1` if you add a step). Return named text states from SQL — `CASE WHEN value <> 0 THEN 'ACTIVE' ELSE 'clear' END` — and the colours and legend come out right.

**A state timeline whose series are not known in advance needs `queryType: "table"` plus `partitionByValues`.** The pivoted one-column-per-series form only works when you can write the columns out at authoring time — fine for `bms_io_state`'s eight IO lines, impossible for diagnostic codes, where which of the 154 appear is a runtime fact. Measured against Grafana 11.3 with this plugin, on a `(time, metric, state)` query:

| shape | result |
| --- | --- |
| `time series` + text `value` | **`No data in response`** — the plugin builds no frame at all  |
| `time series` + numeric `value` | renders, but every row is labelled `-∞+` (see above) |
| `table` + `partitionByValues` | ✅ one row per distinct `metric`, text states, correct colours |

So: return `time`, `metric` and a text `value`, set `queryType: "table"`, and add

```json
"transformations": [
  { "id": "partitionByValues",
    "options": { "fields": ["metric"], "keepFields": false, "naming": { "asLabels": true } } }
]
```

`asLabels: true` puts the series name in a `metric` label, which then needs the **same `displayName` line as a time-series panel** — `"displayName": "${__field.labels.metric}"` — or every row on the timeline is called `value`. (`asLabels: false` with `"${__series.name}"` works identically; pick one and keep the file consistent.) Used by `trouble-codes.json`.

**Aggregating those text states, `MIN()` is severity-first, `MAX()` is not.** SQLite compares text with BINARY collation and `'ACTIVE'` (0x41) sorts before `'clear'` (0x63), so `MAX()` over a bucket containing both returns `'clear'` and a flag that set and cleared inside one bucket renders green. Renaming either label can flip this silently.

**Grafana keys a separate y-scale off each distinct `axisLabel`.** Setting the label on one of three right-axis series produces three stacked right axes. All series sharing an axis must share the label string exactly.

**To break a line across a transport dropout you need `insertNulls`, and `spanNulls` has to get out of its way. They are not independent settings.** `insertNulls: <ms>` ("Disconnect values" in the UI) inserts a null once a series goes that long without a sample. `spanNulls` then decides whether that null survives the frame join. Measured by mutation on `ride-summary.json`'s **Inverter torque** panel, Grafana 11.3:

| `insertNulls` | `spanNulls` | result |
| --- | --- | --- |
| `false` | `60000` | line drawn straight through a 5.3 h dropout — no nulls exist to span |
| `20000` | `true` | **flat line is back** — `true` deletes the nulls `insertNulls` inserted |
| `20000` | `false` | ✅ line breaks at the dropout, normal sampling still continuous |

So `spanNulls: true` **silently cancels** `insertNulls`, and any numeric `spanNulls` above `insertNulls` bridges the gap just the same. Set `insertNulls` to the threshold and `spanNulls` to `false`. The first attempt here set only `spanNulls: 60000` and changed nothing on screen, which is the trap that leads to the wrong conclusion — with `insertNulls: false` there are no nulls in the frame to span, so `spanNulls` alone looks inert and is not.

⚠️ **Several `spanNulls: true` settings in these dashboards are therefore doing the opposite of what their descriptions claim.** "Motor power and torque" credits `spanNulls` for drawing "exactly what was recorded" while in fact holding `motor_torque_nm` flat across BLE dropouts of hours. It matters wherever two independently-transported signals share one axis: a held line next to a live one reads as the two sources disagreeing, which is exactly the "looks like a finding" failure this file warns about elsewhere.

**Pick the threshold off a histogram of that signal's own gaps, not off a percentile.** ⚠️ A percentile will mislead you here. `motor_torque_nm`'s p99 is 1.31 s, which makes 60 s look enormously safe; it is not, because the distribution is not one population with a tail. Over the whole log: 113 358 gaps under 5 s, then only **79** across the entire 5-35 s span, then a distinct **556** sitting at 35-45 s — a recurring hub stall, with the bike moving throughout. A 60 s threshold bridges that whole second population and hides **332 000** inverter rows behind held line segments, against 510 at any threshold from 10 s to 30 s. The valley between the two populations is what you want, and only a histogram shows it. Where there is no valley — the module temperatures below, where a healthy sensor goes 48 minutes between samples — no threshold works and the answer is a dedicated liveness signal instead.

**Never change a provisioned dashboard's `uid` in place.** The file provisioner then fails on every sync with `could not resolve dashboards:uid:… Dashboard not found`, permanently. Change the title instead.

## Querying log-on-change data

The DB stores a row only when a signal changes by more than its per-signal deadband (`src/can/registry.ts`), and `lastLogged` resets on service restart, so the first sample of every signal after a reboot is always written. Three things follow.

**A stat tile bounded by `r.ts BETWEEN $__from AND $__to` reads "No data"** whenever the signal has not changed inside the window — which for a healthy fault flag is most windows, and looks identical to the logger being down. Drop the lower bound (`r.ts <= $__to`) and the tile shows the held value.

**Carry-forward joins need seeding from before `$__from`.** Two signals logged independently never share a timestamp, so pairing them means holding the last known value of each. If the hold only sees rows inside the window, zooming to a stretch where just one of the pair happened to log leaves the other NULL and every derived panel blanks at once.

**Seed a timeseries at _both_ ends.** The left seed alone does not draw. Grafana pins the x scale to the dashboard time range, so a sample from before `$__from` is clipped out of the plot area, and `stepAfter` builds segments between consecutive points rather than extending past the last one — one off-screen point has nothing to pair with, so the panel goes from "No data" to an empty plot, which reads as a rendering bug rather than a data gap. Emit the last known value a second time, restamped at `$__to`:

```sql
UNION ALL
SELECT * FROM (SELECT $__to/1000.0, s.key, r.value
               FROM reading r JOIN signal s ON s.id = r.signal_id
               WHERE s.key = '…' AND r.ts <= $__to ORDER BY r.ts DESC LIMIT 1)
```

A **state timeline needs only the left seed**: its regions run until the next sample or the end of the time range, so the last state reaches the right edge by itself.

**A flat line means "no change larger than the deadband", not "no change".** Where the deadband is large (10 counts on `iso_test_*`, 100 on `lmu_cell_mux`) say so on the panel — otherwise the axis implies a resolution the data does not carry. Signals whose deadband exceeds their real range only ever produce one row per boot, so a count of them is a count of service restarts.

**A silent sensor and a steady one are not distinguishable from the value stream.** A state timeline draws its last region to the end of the range whichever it is — that is the panel type, not `spanNulls`, which only bridges nulls _between_ points. And a bounded `spanNulls` cannot separate them here: a healthy module goes 48 minutes between logged samples at a constant 28 °C in the 2026-08-02 file, so any cutoff short enough to catch a dropout fires constantly on settled hardware. Use a dedicated signal — `lmu_comm_warnings` (0x206) — rather than trying to infer it from silence.

## Generated queries

**`trouble-codes.json`'s code table is generated — do not hand-edit it.** Grafana can see the ride log and nothing else, and the ride log stores `dtc_0044_0 = 1`, not "water pump open circuit", so the two panels that name a code carry all 154 of them inline as a SQL `VALUES` CTE. That copy cannot be deleted without a second datasource, so it is derived instead: `scripts/generate-grafana-dtc.ts` rewrites the `VALUES` list from `src/diagnostics/dtc-table.ts` and nothing else in the file.

```
npm run generate:grafana-dtc   # after any change to the code table
npm run check:grafana-dtc      # the same thing as `--check`; also checks the prose counts
```

`npm test` runs that check along with the rest of `scripts/run-checks.ts`, so a stale dashboard is a red build and not something you have to remember to look for.

It was hand-maintained until 2026-08-16 and it had already gone stale: a change to the water-pump codes in the TypeScript table never reached the JSON, so for a day the dashboard and the phone screen gave this bike's own `dtc_0044_0` two different names — a seized pump on one, an unwired one on the other. (That change was itself reverted on 2026-08-16 once the bike's own mode-03 reply was read; the entry in `src/diagnostics/dtc-table.ts` argues it out.) Nothing looks wrong on screen when a lookup table is wrong; the panel renders a confident name either way. That is the whole argument for generating it.

## Verifying a dashboard before shipping it

Run every `rawQueryText` against `rides.db` with `$__from`/`$__to` and the template variables substituted, and confirm each returns rows. A panel that renders "No data" is indistinguishable from a broken bike, so it has to be ruled out at the query level first. Check `EXPLAIN QUERY PLAN` shows `SEARCH … USING INDEX idx_reading_sig_ts (signal_id=? AND ts>? AND ts<?)`: the only index on `reading` leads with `signal_id`, so a query filtered on `ts` alone scans. SQLite does flatten derived tables and push a `signal.key` predicate down through the join, so a subquery filtered only on `ts` is not automatically a scan — check the plan rather than assuming either way.

## ⚠️ `rides.db` is in WAL mode, and that silently blanks panels

Measured 2026-08-20, replaying a real DC session: a panel rendered **"No data in response"** with an error icon while its SQL, run directly, returned 10 rows. The datasource had come back with `{"error":"database is locked (5) (SQLITE_BUSY)"}` and Grafana surfaced it as an empty panel.

The cause is SQLite's WAL journal read across a Docker bind mount. `docker-compose.yml` mounts the whole repo (`- .:/repo:rw`) and `rides.db` sits at its root, so this is the normal setup, not an exotic one. `PRAGMA journal_mode` on `rides.db` reads `wal` today.

Measured, 17 panel queries × 5 concurrent rounds:

| journal mode | queries errored |
| --- | --- |
| `wal` | **3 of 85** |
| `delete` (rollback) | **0 of 85** |

So roughly **one panel per dashboard load** comes back blank, and a different one each time. Per this file's own argument in §"Every query has to be run" — _"a panel that renders 'No data' is indistinguishable from a broken bike"_ — that is the worst shape a failure can take here: it looks like a finding.

`PRAGMA journal_mode=DELETE` on the database Grafana reads fixes it. The decrypt step that produces the file Grafana reads is the natural place to set it.

⚠️ **Do that on the COPY, never on `rides.db`, and the reason is not the obvious one.** Switching journal mode takes an exclusive lock, which is a nuisance; the real problem is that DELETE serialises every reader against the writer. Measured on the same harness, 5 readers plus one live writer: the WAL copy errored **0 of 85**, the DELETE copy **53 of 85**. WAL exists precisely to prevent that, and `rides.db` has a logger appending to it. DELETE is right only for a static file nothing is writing.

⚠️ **It is the datasource plugin's driver, not SQLite.** The same two databases over the same bind mount, read through CPython's `sqlite3` (SQLite 3.46.1): **0 of 85** at 5 concurrent readers, **0 of 1020** at 20 threads × 3 rounds, and **0 of 85** even with a live writer. This is a `frser-sqlite-datasource` problem, not a "WAL is broken on Docker Desktop" problem — worth stating, because the second conclusion is the tempting one and it is false.

⚠️ **The rate is highly variable.** Six rounds of 17 queries × 5 concurrent gave 1, 32, 6, 1, 6 and 2 errors — 48 of 510 overall. "About one panel per load" is a central estimate, not a ceiling; a bad load can blank a third of the dashboard.

## Rows already in `rides.db` that this repo now decodes differently

Two decoder fixes on 2026-08-16 changed what the code produces, but neither can change what is already stored: the sealed ride log holds the values the Pi decoded at the time, so re-running `decrypt-log.ts` reproduces them faithfully. Grafana reads those rows raw. Both are left as-is deliberately — this is the only copy of the data and correcting it in place is a one-way trip — but the queries below are here so the decision is yours and the SQL is not something you have to re-derive.

**`gps_altitude_m` sign convention (145 rows).** The field is 16-bit two's complement and was read as a 15-bit magnitude plus a sign bit, so a true −1 m was stored as −32 767 (see `src/gps/decode.ts`). **The "Elevation range" tile on `ride-summary.json` computes `MAX − MIN` over raw rows**, so on history it reports a spread of about 32 km. `public/lib/bounds.js` already gates these out of the phone dashboard; Grafana does not gate anything. The mapping is exactly invertible:

```sql
-- inspect first; 145 rows, all between -32756 and -32767
SELECT value, COUNT(*) FROM reading
WHERE signal_id = (SELECT id FROM signal WHERE key = 'gps_altitude_m') AND value < 0
GROUP BY value ORDER BY value;

-- corrected = -32768 - old, for old < 0 only
UPDATE reading SET value = -32768 - value
WHERE signal_id = (SELECT id FROM signal WHERE key = 'gps_altitude_m')
  AND value < 0 AND seq IS NULL;
```

The `seq IS NULL` is what keeps this idempotent and safe to run twice: rows written by a Pi carrying the fix arrive from v2 ride-log segments and have a write-order counter, so a NULL `seq` means "decoded before 2026-08-16" — which is exactly the set that needs correcting.

**49 772 rows stamped 2060** (`ts` between `2844182125379` and `2859221509504`). One corrupt GPS frame stepped the Pi's clock 34 years forward and the anti-thrash cooldown held it there; see the Clock section of the top-level README. Their `gps_epoch_s` is intact, so the true time is recoverable per row, but there is no single offset to subtract — the two bursts are 34 years and different months apart. Easiest is to exclude them from any range that matters:

```sql
AND r.ts < 2000000000000   -- anything past year 2033 is the 2060 corruption
```

⚠️ **`charge-manager.json` and `route-map.json` carry that guard throughout, and so do the three queries behind `ride-summary.json`'s "Inverter torque — commanded vs delivered"; no other panel does.** They are safe only for as long as their default `to: now` range is left alone, because `now` is before 2060 and the misdated rows sort after it. Change one to an absolute range ending past 2033 and two things break at once: every axis stretches to 2060 and squashes the real data into a sliver at the left, and — worse, because it looks like an answer — the held-value tiles that deliberately drop their lower bound (`r.ts <= $__to`, §Querying log-on-change data above) return a 2060 row. Measured on the current `rides.db`: `odometer_can_km` held to a `$__to` in 2060 reads **17 497.1 km stamped 2060-08-08** instead of the true latest **17 866.4 km from 2026-08-09**. `pack_a` has 1 740 such rows, `dc_v` 492, `pack_v` 301, `mains_a` 254. Retrofitting the guard to the seven dashboards that still lack it entirely is a mechanical change nobody has made yet, and it is not free of judgement — a few panels exist to inspect data health and might legitimately want to see the corruption.

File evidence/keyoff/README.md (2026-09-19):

# Reduction scripts for the key-off and clock-trust measurements

Every figure in `docs/power-cuts.md` §7 and `docs/ride-log-clock.md` is generated by these, not retyped. Issues #57 and #188.

```sh
# 1. reduce the candump archive to its events (~12 min, one sequential pass, 16 GB)
cd ~/Documents/cool-eva-archive
ls capture-*.log capture-*.log.gz buttons-2026-08-19.log charge-2026-08-02-real.log charge.log \
   dtc-2026-08-02-*.log energica_probe.log energica_ride.log ride-1.log \
   ride-2026-08-02.log > /tmp/files.txt
: > events.txt
while read -r f; do
  echo "F $f" >> events.txt
  # `gzip -dc`, not `zcat`: on a Mac zcat has historically meant .Z. Captures written by the
  # Pi are .log.gz since #289, and a cut one exits non-zero — which is the NORMAL ending
  # here, hence `|| true`, with reduce-captures.awk's own `NF < 6` guard for the last line.
  case "$f" in
    *.gz) LC_ALL=C sh -c "gzip -dc '$f' || true" | awk -f <repo>/evidence/keyoff/reduce-captures.awk >> events.txt ;;
    *)    LC_ALL=C awk -f <repo>/evidence/keyoff/reduce-captures.awk "$f" >> events.txt ;;
  esac
done < /tmp/files.txt
python3 <repo>/evidence/keyoff/tail-shape.py $(cat /tmp/files.txt) > tails.jsonl

# 2. the figures
python3 <repo>/evidence/keyoff/capture-figures.py events.txt tails.jsonl
python3 <repo>/evidence/keyoff/clock-figures.py <a read-only copy of rides.db>
```

`figures.txt` beside this file is the committed output of step 2, so a reader can check a number in the docs without the 16 GB.

⚠️ **`tail-shape.py` reports a different shape for a `.log.gz`.** The trailing-NUL run and the 4096-byte boundary are raw-file measurements and mean nothing on a compressed capture, so those rows carry `members`, `cutMember` and `decoded` instead of `nulls`. Every figure in `docs/power-cuts.md` §7 computed over `nulls` is therefore about the **uncompressed** archive only, and will silently cover a smaller share of the corpus as compressed captures arrive — count them rather than assuming the denominator held.

## Two traps that cost real time, both caught in review

⚠️ **candump's column width moves _within_ one file.** `capture-20260808-193722-988ac089.log` prints `can0  101   [8]` early and `can0       101   [8]` later, so a fixed-space `grep ' can0  101 '` returns 234 020 of its 576 168 `0x101` frames — **59 % dropped, no error**. Everything here selects on `$4`, never on spacing.

⚠️ **Guard `NF`.** `capture-20260807-213353-999f16f6.log` ends `(2026-08-07 21:38:22.623151)  can0  101   [8]` with the data bytes cut off mid-line by the power cut. Ungarded that reads as a state change at the file's last instant and moves a capture between populations — and a truncated last line is the _power-cut signature itself_ (`tail-shape.py`), so it is common, not exotic.

⚠️ **The wall clock in these files steps.** 40 of the 97 files carry a discontinuity, and an interval measured across one is not a duration — `docs/can-0x101.md` records a 317 s figure retracted to exactly this. Every interval here is refused if one lies inside it, **including an inverted one**: a backward step puts `end` before `start`, and a range test that does not check for that silently passes the worst interval in the corpus.

## Corpus, stated rather than left to a glob

255 files: 246 `capture-*.log` plus `buttons-2026-08-19.log`, `charge.log`, `charge-2026-08-02-real.log`, the two `dtc-2026-08-02-*.log`, `energica_probe.log`, `energica_ride.log`, `ride-1.log`, `ride-2026-08-02.log`. 97 carry frames.

- `ride-1.log` and `ride-2026-08-02.log` are byte-identical, so one file is counted twice.
- `can_log-2026-06-14.txt` is excluded: epoch-and-hex framing, not `candump -tA`.
- `ride-captures3/`'s 59 files are excluded as duplicates — all 59, across all seven of its boot ids, duplicate top-level files, so no boot is missed and no terminal capture is misidentified.

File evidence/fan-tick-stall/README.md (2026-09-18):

# Did the fan loop ever stop applying its own answer?

Issue [#282](https://github.com/danieltroger/cool-eva/issues/282). The **sweep** figures in `docs/fan-control.md` §9 — sample counts, held divergences, the grace sweep, the mutant column — are generated by `curve-lag.py`, not retyped, and its committed output is `figures.txt`.

⚠️ **The rest are not.** The row counts, the clock-step arithmetic, the BMS-uptime edges, the coolant and current figures and everything in `docs/ride-log-clock.md` §6 are one-off queries against `rides.db`, quoted in the docs with the query or the `seq` that produced them. Two of them were wrong in the first version of that section for exactly the reason this split exists: nothing regenerates them, so nothing catches them going stale. Re-derive before trusting.

```sh
python3 evidence/fan-tick-stall/curve-lag.py > evidence/fan-tick-stall/figures.txt   # ~35 s
```

It reads `rides.db` **read-only** (`RIDES_DB=` overrides the path) and needs nothing else — no captures, no network, no Pi.

## What it measures

For every boot, what the fan loop decided against what it had already commanded, on both branches that set a duty: the pack-temperature curve, and a DC session. A divergence is opened when the two disagree and closed when they agree again; what is reported is how long one was ever **held**.

## Three things it must keep doing

- **Group by `session_id`, order by `seq`.** #282 exists because four boots' rows were read off one `ts` axis. `docs/ride-log-clock.md` §6.
- **Judge the DC branch too** — while knowing what that arm cannot do. A detector that only judges `PACK_TEMPERATURE` is silent on the regime #282 was actually about, and the silence is self-concealing: a loop that dies while the reason is `DC_SESSION` leaves that reason latched under log-on-change, so the sample never becomes judgeable. ⚠️ But **all three of the DC arm's inputs are outputs of the loop under test**, so it cannot see a dead loop either — it is a branch-consistency check, and only the curve arm, whose `batt_temp_hi` is registry-driven, discriminates. `docs/fan-control.md` §9 says which claim rests on which.
- **Find the clock steps over the whole table, at contiguous `seq`.** Deriving them from the script's own sparse row stream reads every quiet sampling gap as a step and refuses exactly the intervals worth measuring. That bug shipped once: it returned **zero** mutation kills at a 30 s grace while looking healthy at 5 s.

## The mutant

`BIAS_C` is a magnitude in degrees, not a flag. The committed column is `BIAS_C=7`; the real measurement is `BIAS_C=0`, which `main()` takes for the baseline column itself. A detector that cannot fire proves nothing, so the two columns are printed side by side rather than the baseline alone:

| | curve arm | DC arm |
| --- | --- | --- |
| real archive, 30 s grace | 0 held | 0 held |
| mutant +7, 30 s grace | 35 held, 13 refused | 49 held, 9 refused |

35 + 13 = 48, which is what the same sweep with no step guard at all reports — so the guard is subtracting steps and nothing else.

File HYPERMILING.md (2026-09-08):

# Hypermiling view — recommendations

Design notes for a range-maximising view, written from the BMS's own configuration and the LiBAL Application Engineering Manual. The frame decodes referenced below are all implemented in `src/can/decode-bms.ts`; the reverse-engineering notes and the OEM manuals they came from are local-only and not in this repo.

**Division of labour:** the backend logs _measured_ values only. Every derived quantity below is the frontend's job. Nothing here should become a logged signal.

---

## 1. The core insight: range is set by one cell, not by the pack

The pack is 81 series positions (11 LMUs: four with 8 cells, seven with 7). The BMS cuts discharge on the **minimum cell voltage**, not on pack voltage or SOC. Everything else is an average that hides the one cell that actually ends the ride.

Two consequences worth building the whole view around:

- **Cell spread is range you already paid for and cannot use.** `cell_spread_mv` (ΔV, `0x205`) is the gap between best and worst cell. When the worst cell hits the floor, the rest of the pack still holds that much unusable charge. On this bike the weak cell is **#68** and the strong one is **#20** — note this is the _opposite_ of what the original decode said before the BMS config was read; bytes 2 and 3 of `0x203` were swapped.
- **SOC is the wrong gauge near empty.** It comes from coulomb counting plus an OCV model, and the OCV table in the config was never re-characterised for the P32B cells. Below roughly 20 % the view should stop leading with SOC and lead with min-cell headroom instead.

---

## 2. "How close am I to cutting out" — do it properly

The naive version (`cell_min_mv − cutoff`) will cry wolf on every hard acceleration. Three things make it honest:

### a) Compensate for sag

Voltage under load is not voltage remaining. Sag is roughly ohmic:

```
sag_mv_per_cell  ≈ pack_current_a × pack_resistance_mohm / 81
cell_min_rest_mv ≈ cell_min_mv + sag_mv_per_cell        (while discharging)
```

`pack_resistance_mohm` here is **not** the BMS's `0x206` b0-1 estimate, which is unusable — see `docs/pack-resistance.md`. It is measured by regression of `pack_v` on `pack_a`, or modelled off pack temperature. `pack_current_a` is `0x200` bytes 6–7 (check the sign convention in `decode.ts` — it's signed, charge vs discharge). Amps × milliohms gives millivolts directly, so the units work out with no scaling factor.

This matters more than it sounds: at 100 A with a 100 mΩ pack that's ~123 mV per cell of pure sag — comparable to the entire margin you're watching. Show **both**: instantaneous (what the BMS sees, what will actually trip) and sag-compensated (what you actually have left).

### b) Show the dwell, not a binary alarm

`DischargeModeUnderVoltageCutOffTimer` is **60 s**. The minimum cell must stay below the threshold for a full minute before the contactors open. A dip during a hard pull is not a cut-out. Show a dwell bar that fills while under threshold and drains when back above — that turns a scary flicker into actionable information ("you have 45 s of this left").

### c) `allowed_discharge_a` is the earlier and better warning

`0x202` bytes 4–5 is the BMS's own live current limit. It falls **before** the voltage floor is reached, and it also drops for cold, heat and low SOC. Voltage headroom tells you where the cliff is; allowed-current tells you the BMS is _already_ throttling you. As a headline "am I being limited" indicator it beats voltage.

Note this is the one signal that can never go stale — see §6.

---

## 3. Efficiency: where the energy actually goes

### Resistive loss is a first-class hypermiling lever

```
i2r_loss_w        = pack_current_a² × pack_resistance_mohm / 1000
i2r_loss_fraction = i2r_loss_w / (pack_kw × 1000)
```

At 100 A / 100 mΩ that's ~1 kW thrown away as heat. Because it scales with **current squared**, halving your current quarters the loss — which is the single most direct visualisation of why gentle riding wins. A live "% of pack output being burned as heat" readout is more motivating than a Wh/km number that only settles over minutes.

This also ties into the watercooling project: that 1 kW is exactly what the loop has to remove, so the same number explains both range and coolant ΔT.

### Consumption

- `inst_consumption_wh` (`0x025`) is the bike's own instantaneous figure — good for a needle, too twitchy for decisions. Show a rolling median alongside.
- **Use `0x661` bytes 0–2 for remaining energy once the new config is flashed** — 1 Wh resolution, versus the 1 kWh field on `0x205` and the bit-15-flagged word on `0x10A`. Far better for a range-remaining estimate.
- Range estimate: rolling Wh/km over the last few km, applied to remaining Wh. Show the horizon used ("at your last 5 km"), because a single number invites false precision.

### Regen you are not capturing

`allowed_regen_a` (`0x202` bytes 6–7) against the configured ceiling of 120 A. It derates at high SOC and at temperature extremes. If you top out at 100 % and head down a mountain, regen is unavailable and you'll be on the brakes — worth surfacing _before_ the descent, not during. The configured curve in the current config: full 120 A from 10 °C to 45 °C, tapering to zero at 55 °C, and on the cold side nothing below −10 °C.

---

## 4. Temperature

- `0x660` gives **which** LMU is hottest and coldest (indices), plus average pack temperature.
- `0x664` carries per-LMU battery temperature (BAT1) multiplexed by LMU number — the first time module-level temperature is available. Caveat: **LMU 6 and LMU 8 have no battery temperature sensor enabled**, so they will never report one. That is configuration, not a fault.
- Cold pack means higher resistance, which means more I²R loss and more sag, which means less range _and_ an earlier cut-out. With coolant in/out already logged, a "pack efficiency vs temperature" view is directly reachable and would justify the watercooling loop empirically.

---

## 5. Suggested layout

**Primary (always visible)**

1. Min-cell headroom above cut-off — instantaneous and sag-compensated, with the dwell bar
2. Allowed discharge current vs the 400 A ceiling — the "am I limited" bar
3. Rolling Wh/km with the averaging horizon stated
4. Remaining energy in Wh, and range at the current rolling rate

**Secondary**

5. I²R loss as % of output
6. Cell spread ΔV, with min/max cell index (min is the one that matters)
7. Hottest LMU index + average pack temp; coolant in/out ΔT
8. Regen headroom — allowed regen vs 120 A

**On demand**

9. Per-cell voltage strip, 81 bars, weakest highlighted — once the new config is flashed
10. Error/warning flags, only when non-zero

---

## 6. Traps

- **Don't trust `0x665` blindly.** It's the configured cut-off broadcast as a _literal constant_, because the BMS exposes no memory address for its own configuration thresholds (the CAN memory map is 82 entries, all live measurements or command registers). It's stamped in at config-build time and cannot drift from the config it ships in — but it _can_ be desynced by editing limits in the Diagnostic Software GUI without regenerating the file. If `0x665` and observed cell voltages ever disagree, suspect a stale config, not a decode bug. `allowed_discharge_a` never has this problem.
- **Don't average the per-cell frames across LMUs.** `0x662`/`0x663`/`0x664` are three separate messages and the BMCU advances to the next module between them. Always key cells off the LMU number in the _same_ frame.
- **Don't treat 0 mV as a cell reading.** LMUs 5–11 have only 7 cells, so the cell-8 slot is meaningless for them.
- **`charge_state` is a bitfield, not an enum.** `1` = Discharge, `2` = Charge, `16` = Idle. Testing `!== 1` for "charging" flags Idle as charging.
- **Rate mismatch.** `0x200`/`0x203` are 20 Hz, `0x202` 10 Hz, `0x205`/`0x206`/`0x660`/`0x661`/ `0x665` 1 Hz. Anything combining a 20 Hz and a 1 Hz signal is only as fresh as the slow one — don't present a 1 Hz-derived number as instantaneous.
- **Sag compensation is a model, not a measurement.** `pack_resistance` lumps in cabling and contactors, and is itself either a live regression or a curve read off pack temperature (`docs/pack-resistance.md`). Treat the compensated figure as an aid, never as the authority on whether you're about to cut out — the instantaneous value is what trips the BMS.

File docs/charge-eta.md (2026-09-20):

# Charge ETA — when the bike gets there

The Charge tab's "to N %" tile. `public/lib/charge-eta.js` is the arithmetic, `public/views/charge-eta.js` the tile, `scripts/check-charge-eta.ts` the check. Nothing runs on the Pi for this: `soc`, `pack_kw` and `charge_soc_limit_pct` are already on the wire.

**Energy ÷ power**, not SOC-step timing. That is a measured choice, not a preference — see below.

## Why not time the SOC steps

The first design timed the intervals between whole-percent `soc` transitions and took the median of the last three. The argument for it was real: `soc` is whole percent, so a rate taken by **differencing two levels** carries ±1 point of quantisation, and over a small move that is most of the answer. (That is not hypothetical — it produced a 4× wrong charging rate in an overnight control script on 2026-09-19 and would have raised the bike's charge current for nothing.)

But the alternative it was being defended against was the wrong one. **Energy ÷ power has no SOC term at all**, so it was never exposed to that error. Replayed against the archive's own charging runs, predicted ÷ actual:

| | median | p10  | p90  |
| --- | --- | ---- | ---- |
| energy ÷ power, AC | **1.00** | 0.96 | 1.04 |
| step median-of-3, AC | 0.92 | 0.89 | 1.07 |

Unbiased, with half the dispersion, and it needs no ring, no listener, no new signal and no state that a service restart destroys.

## What a SOC point costs

**~199 Wh**, by integrating `pack_kw` across the archive's charging runs. Two independent passes: **AC n=10 median 198.8, DC n=34 median 199.7**, measured between SOC _transition instants_ so no level-differencing enters; and an earlier per-run pass at DC n=31 median 196, AC n=5 median 185. The shipped constant is **199**.

⚠️ **It is a compromise, and the residual bias is SOC-dependent.** Per band, DC rises monotonically 188.6 Wh (20–29 %) → **208.1 (80–89 %)**, so 199 runs ~4 % optimistic exactly where a charge limit sits. The tile is good to roughly ±5 % — minutes on AC, seconds on DC. A per-band table would buy that back and is not worth the fit.

⚠️ **It is not `residual_energy_wh ÷ (soc/100)`.** That field is **discharge-side**: it says what the pack will give back, and charging a point costs more than discharging one returns. It implies 16.0 kWh — 160 Wh a point — and using it makes the ETA ~18 % optimistic before any taper. `soh` reads 100.0 in all 320 archive rows, so the gap is charge/discharge accounting, not degradation.

⚠️ **Nor is it the 21.5 kWh nameplate**, which is the gross figure and is wrong the other way.

The constant is stated **per point** rather than as a capacity on purpose: calling it a capacity is what invited both of those errors, and it invites the next reader to "improve" it by recomputing `remainingWh() / soc` live — which reintroduces a SOC-dependent bias for nothing. For the record, that ratio drifts 15.29 → 16.22 kWh from empty to full (6.1 %, and flat at the top).

**Corroboration:** 199 Wh ÷ 230 W (1 A at 230 V) = 52 min a point, and the archive's slowest real charge runs **38.4 min/point at `pack_kw` 0.3**, which the same arithmetic puts at 40. They agree to a couple of minutes a point.

⚠️ **`bms_remaining_energy_wh` reads 0.0 in all 317 archive rows on this bike.** `remainingWh()` in `public/lib/derive.js` prefers it and falls through to `residual_energy_wh` because `positiveOrNull` rejects a zero. Any statement about "the pack's own remaining-energy field" on this bike is about the second one.

## The boundary is at target 100, and nowhere else

Predicted ÷ actual, **indexed by the target asked for**:

| target | DC median | AC median |
| --- | --- | --- |
| 60 % | 0.97 | 1.03 |
| 80 % | 0.90 | 0.98 |
| 88 % | 0.81 | 0.95 |
| 90 % | 0.82 | 0.96 |
| 95 % | 0.79 | 0.94 |
| 99 % | 0.68 | 0.92 |
| **100 %** | **0.39**  | **0.78**  |

One discontinuity, between 99 and 100. So every target up to 99 gets a **point estimate**, and only 100 gets a **lower bound** — "not before HH:MM".

⚠️ **The 99 → 100 step itself is thin evidence, and an earlier draft of this file overstated it.** Re-derived: **7 up-steps exist archive-wide, all AC, none DC** — 0.2, 0.8, 1.0, 3.3, 14.7, 15.6 and 78.5 min, three of them not charging at the time. Charging-only the median is ~14.7 min against 98 → 99's ~6.9, i.e. **about 2×**, not the "5–15×" this file used to claim — and the "DC 7.5 and 24.1 min" it cited **do not exist**: there are no DC 99 → 100 transitions in the archive at all. The bound is still right, because the predicted/actual table above is computed over the whole approach to each target and drops from 0.92 to 0.78 on AC at 100. The last step's own durations are simply too few to carry the weight the earlier wording put on them.

⚠️ **This is not `SOC_RATE_TRUSTED_BELOW` (88).** That constant is in `src/charge/soc.ts` and says in its own comment that it was measured for a **trailing-rate DC controller**. Borrowing it would refuse a real time for targets 90–99 — exactly the range `charge_soc_limit_pct` sets. A different instrument measures its own boundary.

⚠️ And the sentence "every measurement above the knee runs 2–4× long", which an earlier draft of this feature carried with a ⚠️ on it, is **false**. It came from reading the table above indexed by where the prediction was made rather than by its target. Recorded here because a wrong fact wearing a correction's costume is the expensive kind.

## No correction factor

DC runs 0.79–0.90 of actual below the boundary, which looks like a factor worth applying and is not. DC's 18 % is **2.4 minutes**, because a DC charge to 90 % takes 18; AC's 4 % is 6.4 min on a 214-min wait. It is not a scale error anyway — 0.97 at target 60 decaying to 0.68 at 99 is the taper leaking in, which a median factor cannot represent — and the pain is in the dispersion (DC p10 −15 min), which a factor cannot touch either.

## When it says nothing

No SOC · no target · already at or past it · `pack_kw` below **0.1 kW**.

That floor is one rule covering three things — not charging, a stalled charge, and a discharging pack — because they are the same question: is enough going in to divide by. It is a floor rather than a zero test because 0.02 kW returns a forty-day ETA, which is not an answer. ⚠️ It is also the stall rule, and it has to be: `charge_manager_state` does **not** move during a stall (it stayed put through all five of the archive's longest).

## Smoothing `pack_kw`

Median over 60 s from the store's ring, falling back to the newest reading below 3 samples.

⚠️ **`pack_kw` does not reach the browser at 20 Hz.** `notifyChange` sits inside `record()`'s deadband branch, so the patch stream is the ride log's row stream, gated at 0.05 kW — measured **DC 28 rows/min, AC 7.2, AC p10 0.5**. A 60 s window can legitimately hold **zero** samples, and the fallback is correct rather than a concession: silence on a log-on-change signal means the value is unchanged, not missing. Peak-to-peak inside 60 s is 3–5 %, so the window is not doing much work on DC either — it is there to stop a taper step jumping the readout.

## How the replay judges itself

A prediction may use only the samples that existed at the instant it is made — no look-ahead.

⚠️ Stalls are excluded as **predictions, not runs**, by the tile's own `pack_kw` floor, so both sides use one definition. Excluding whole runs would have thrown away over half the corpus and, more importantly, would have hidden the taper the boundary exists for: of the outlier intervals, those at soc ≥ 95 and 88–94 are the taper, a third below 88 still have `pack_kw > 0.2`, and only about 15 of 38 are genuine stalls.

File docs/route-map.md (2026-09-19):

# Route & charging map

`grafana/dashboards/route-map.json` — where the bike went, and where it charged, from the decrypted ride log. Related: `grafana/README.md` (the datasource's own traps), `docs/charge-manager.md` (what the charge signals mean), `docs/dashboard-decisions.md`.

Everything below was measured against the 2026-09-07 decrypt (15 477 057 readings, 2026-08-02 → 2026-09-07), **except the charge-stop corroboration section and [Materialised once, not per load](#materialised-once-not-per-load)**, both measured against the archive as it stood later (2026-08-02 → 2026-09-12, 35 119 149 readings) and saying so where the numbers differ. ⚠️ Where an older figure and a newer one measure the same quantity, both are kept with their vintage rather than one overwriting the other: the archive grows, and a number with no date attached is the one that goes quietly wrong. No coordinates appear in this file or in the dashboard JSON, and that is deliberate — see [No coordinates anywhere](#no-coordinates-anywhere).

## Materialised once, not per load

**The track is no longer rebuilt when you open the dashboard.** `scripts/import-ride-log.ts` computes it over the whole archive into a `route_track` table (`ts INTEGER PRIMARY KEY, lat, lon, speed`), and the panel reads that. Everything in the three sections below — the carry-forward, the per-second collapse, the shape despiker — is unchanged; only where it runs moved, from `grafana/dashboards/route-map.json` into `scripts/route-track.ts`.

Why it was worth doing. Measured 2026-09-15 against a copy of the 2026-09-12 archive, one target per fresh process, four runs each, warm page cache:

| target | panel | before (first / median) | after (first / median) |
| --- | --- | --- | --- |
| **A** | the track itself | 4 608 / **1 405 ms** | 95 / **68 ms** |
| **F** | "GPS points mapped" | 1 481 / **1 415 ms** | 70 / **67 ms** |
| the other eight | charge stops, rides, tiles, waypoints | 1 506 ms together | unchanged |
| **all ten** | | **4 326 ms** | **1 740 ms** |

`F` is `A` wrapped in a `COUNT(*)`, so before this the same six-CTE pipeline over 35 M readings ran **twice per load** and was 65 % of the dashboard's SQL. ⚠️ Those are warm-cache numbers on a laptop that had just been hammering the file; on a genuinely cold page cache the same A measures ~5 s and, unhelpfully for this table, so does `H` (Rides, 4 597 ms cold against 669 ms warm). **`H` is untouched by this change** — it counts raw `gps_lat` rows and never used this pipeline — and it is the next candidate.

### What it is worth in the browser, which is the number that matters

SQL times are not what Daniel waits for. Measured 2026-09-15 in a headless Chrome against Grafana 11.3.0 in Docker (`docker-compose.yml`'s pinned image), the same 2.5 GB database both ways, `now-90d → now`, cache-bypassing reload, three runs each. "Painted" is instrumented rather than eyeballed: a script installed before any page script polls `requestAnimationFrame` and records the first frame where the geomap's OpenLayers canvas has real pixels in it **and** every `/api/ds/query` has already returned.

| | before | after |
| --- | --- | --- |
| time to a **painted map**  | 12 306 / 12 178 / 11 818 ms → **12.2 s** | 4 103 / 4 179 / 4 154 ms → **4.2 s** |
| last query response | 11 020 / 10 895 / 10 522 ms → **10.9 s** | 2 875 / 2 955 / 2 957 ms → **3.0 s** |
| slowest two panel requests | **9.4–10.5 s** | 2.1–2.4 s |
| DOMContentLoaded | ~350 ms | ~370 ms |

**12.2 s → 4.2 s to a map you can look at**, and the two ten-second requests are gone. What is left is the charge-session and Rides panels, which this change does not touch.

⚠️ The 11 243-point render is **not** the bottleneck at this size: the gap between the last query returning and the canvas painting is ~1.2 s either way, before and after, on a layer that styles every point as its own OpenLayers feature. That budget is what [Thinning](#thinning) exists to protect and it is still doing its job — **180 563** points in the imported 2026-09-15 archive this browser run used (the SQL table above is the older 2026-09-12 one, at 146 150), both well past the ~68 000 at which the layer was measured to stop painting entirely.

What it costs, on the 2026-09-12 archive (`dbstat`): **146 150 points, built in 4.8 s, 7 258 112 B on disk** — 4 575 232 B of table plus 2 682 880 B for the `ts / 1000` unique index below, so ~50 B a point, not the ~31 B the table alone suggests. Rebuilt from scratch on every import rather than appended to. An incremental build would have to reason about which points a new fix un-spikes; a full rebuild is five seconds beside a twenty-minute decrypt.

`ts` is the rowid, so the panel's `WHERE ts BETWEEN` is a `SEARCH route_track USING INTEGER PRIMARY KEY` range scan. The **per-second collapse is enforced by a unique index on `ts / 1000`**, not by that primary key: `ts` is milliseconds, so two rows in one second are two perfectly legal rowids and a constraint there could never fire.

### What this changes about the drawn track, measured rather than assumed

Not nothing, and the honest statement is per-window. The old query reached ±10 minutes past the window's edges to seed the carry-forward and to give the despiker a neighbour on each side. A table built over the whole archive has no window at all, which cuts both ways:

- **The despiker gets strictly stronger.** [Both window edges need slack](#both-window-edges-need-slack-not-just-the-lower-one) exists because a point with no successor is never tested, which used to mean the last point of _every_ window. Now the only untested points are the archive's own first and last.
- **The carry-forward is no longer truncated**, so a window that opens more than 10 minutes after the last longitude row now draws points the old query dropped.

Old query against new, same database, same ranges:

| window | old | new | timestamps in both | |
| --- | --- | --- | --- | --- |
| default `now-90d` | 11 243 | 11 243 | 11 243 | **identical** |
| whole archive + slack | 11 243 | 11 243 | 11 243 | **identical** |
| 1 h mid-ride | 2 580  | 2 580  | 2 580 | identical |
| 10 min mid-ride | 498 | 498 | 498 | identical |
| 6 h | 8 157  | 8 158  | 8 157 | +1, a superset |
| last 24 h of data | 7 740  | 7 748  | 7 740 | +8, a superset |
| one ride day (09-07)  | 11 818 | 11 820 | **0** | +2, and every drawn point moves |
| one ride day (09-09)  | 9 631  | 9 632  | **0** | +1, and every drawn point moves |

The zero column is the interesting one and it is not a bug: when the stride is 1 every extra row is simply an extra point, but on a ride day the stride is 2, so **one more row flips the thinning phase and the sample lands on the other point of every pair**. Same track, different sample of it. The extra rows are `gps_speed_kmh`-only timestamps at the very start of the data, which the 10-minute seed could not pair with a position and an unbounded carry-forward can.

### ⚠️ The carry-forward has no upper bound, and it never did

Worth writing down because materialising it makes it apply at every zoom level rather than only where a 90-day window had already swallowed it. A point is emitted at _each_ signal's own timestamp with the other axis carried forward from whenever it was last logged — with no staleness limit. Over the archive's 146 193 per-second rows, the age of the older half of each position:

| the carried component is older than | points |
| --- | --- |
| 30 s | 6 463 |
| 5 min | 813 |
| 1 h | 80 |
| 1 day | 17 |
| worst | **1 201 404 261 ms ≈ 13.9 days** |

The despiker removes 43 of the 146 193, so essentially all of these are drawn today and were drawn before this change too, on the default range. It is the same argument [A charge stop is not a measured position](#a-charge-stop-is-not-a-measured-position) makes about inherited fixes — except that stop reports its `Fix age` in minutes and colours the pin by it, and the track says nothing at all. **Not fixed here**, because a staleness cutoff changes which points the map draws and wants its own derivation; recorded so it is not re-discovered as a surprise.

### The file Grafana reads is left in rollback journal mode

`PRAGMA journal_mode = DELETE`, set by the import step as its last act on the finished database. `grafana/README.md` §"`rides.db` is in WAL mode, and that silently blanks panels" measured the datasource erroring **3 of 85** queries over a WAL file and **0 of 85** over a rollback one, with a variable rate that reached 32 in one round, and named "the decrypt step that produces the file Grafana reads" as where to set it. That step now exists. The same section's warning is satisfied by construction: DELETE is wrong for a file a logger is appending to (53 of 85 there), and this one is static by the time the pragma runs.

### If the table is missing — measured, because guessing at this was wrong twice

A rebuild that skips the materialiser leaves no `route_track` at all, because `scripts/decrypt-log.ts` refuses an existing `--out` and therefore starts from a fresh file.

⚠️ **`--force` is the exception, and it is the bad one.** It appends into the existing file instead, so the table survives — **stale**, describing an archive that has since grown — and `initDb` puts the database back into WAL on the way through. Measured 2026-09-15 on a small archive: before, `route_track` 1 point / 308 readings / `journal_mode=delete`; after `decrypt-log.ts --out <same file> --force`, `route_track` **still 1 point** while `reading` had doubled to 616, and `journal_mode=wal`. So that path has no error badge at all — an out-of-date track drawn as if it were current, plus the panel blanking `grafana/README.md` measures at 3 of 85 queries. `info.route_track_built_at` is the only tell, and nothing on that path reads it. Re-run `--materialise-only` after any `--force`.

Dropped the table from a real 2.5 GB archive and reloaded the dashboard, 2026-09-15:

- **exactly two panels** show a "Panel status" error badge in their header — _Route and charge stops_ and _GPS points mapped_, which are the two that read the table;
- the datasource returns `SQL logic error: no such table: route_track (1)` with `"status": 500`;
- the map **still draws**: basemap tiles, charge-stop pins and waypoint stars are all there, and only the track is absent. Distance, Charge stops and Energy charged are unaffected.

⚠️ So it is neither the silent blank `grafana/README.md` warns about under §"`rides.db` is in WAL mode" nor a page that refuses to load. It is a badge on a map that otherwise looks finished — which is exactly the shape that gets missed, so it is worth knowing that the repair is one command and takes four seconds:

```bash
node --experimental-strip-types scripts/import-ride-log.ts --materialise-only rides.db
# route_track: 180 563 points in 4 247 ms
```

`info.route_track_built_at` records when the table was last built, and the import prints it for the database it is about to replace.

## Reconstructing a track from two independent signals

`gps_lat` and `gps_lon` are **separate log-on-change signals with independent deadbands**. They share a millisecond whenever the decoder completes a fix and both moved — but a heading that only moves one of them logs only that one. Over the archive:

| | 2026-09-07 decrypt | 2026-09-12 archive |
| --- | --- | --- |
| `gps_lat` | 97 868 | 191 793 |
| `gps_lon` | 100 277 | 203 694 |
| sharing an exact timestamp | 80 774 | 157 690 |

So an inner join on equal `ts` silently drops **17.5 % of the track** — **17.8 %** on the later archive. Both are quoted because the ratio is a property of the two deadbands rather than of the corpus, and it did not drift as the archive doubled. Each signal is carried forward onto the other's timestamps instead. SQLite has no `IGNORE NULLS`, so the carry-forward is expressed as "the timestamp of the last non-null", joined back to the row holding it.

⚠️ **The 10-minute seed below `$__from` is gone, along with the window it seeded.** `grafana/README.md` §_"Carry-forward joins need seeding from before `$__from`"_ is why it was there — a window opening mid-ride starts with a latitude and no longitude and draws nothing — and that trap is still live for every other query in this repo. It no longer applies to the track: `scripts/route-track.ts` carries forward across the whole archive once, so there is nothing to seed. What that changed about the drawn points is measured in [Materialised once, not per load](#materialised-once-not-per-load).

### One point per second, and why it matters more than it sounds

The per-millisecond pivot emits a row at **each signal's own timestamp**, so a latitude row and a longitude row 1 ms apart become two points a few metres apart — a staircase.

That staircase is not a cosmetic problem. It destroys any speed-based outlier test: 7 m in 1 ms reads as 25 000 km/h. Of the 117 370 consecutive steps on the per-millisecond pivot, **4 718 imply over 200 km/h** — essentially all of them this artefact rather than bad data, which is why a first attempt at despiking on implied speed rejected them wholesale. Collapsing to the last exact sample of each second removes it, and drops the archive to 65 483 points.

## Despiking by shape, not by speed and not by coordinate range

The decoder occasionally produces a longitude carrying an **extra leading digit**, landing it roughly 100° away from the fixes one second either side of it. Three of these exist in the archive. (The values themselves are not reproduced here, for the same reason the dashboard carries no coordinates.)

**A coordinate range gate would catch them and is the wrong tool three times over.** Such a value is a perfectly valid longitude, so the test is really a geography test; a `BETWEEN` in a committed dashboard tells anyone reading the repo which part of the world this bike is ridden in; and — the strongest of the three — **not every corrupt fix leaves the plausible box.** The archive contains single fixes that jump 0.3 km, 1.4 km, 4.8 km and 420 km out and straight back, all of them well inside any latitude/longitude bounds you would think to write. A range gate cannot see those at all.

A spike is defined by **shape** instead: the point sits far from both neighbours _while the neighbours agree with each other_. That third clause is what makes the test safe with no assumption about speed or sampling rate — when the bike is genuinely carried somewhere between two fixes (a trailer, a ferry, an overnight gap), the point after the gap is also far from the point before it, the neighbours **disagree**, and the real position is kept. Only a lone excursion away from a track that continues undisturbed is thrown out.

The comparison is **scale-free** — "sticks out by more than 5× what the neighbours are apart" — rather than a tuned distance, because any fixed threshold is simultaneously too tight for a parked bike and too loose for a moving one.

It carries one absolute floor, and that floor is not a redundant belt. The ratio **degenerates exactly where the neighbours converge**, which is every second the bike sits still with the hub awake: `d(prev, next)` approaches zero, and ordinary GPS jitter then satisfies any ratio you pick. Measured over the archive's 65 481 points:

| rule | points rejected |
| --- | --- |
| ratio alone (5×) | 280 |
| ratio + 220 m floor | **17** |
| earlier absolute-only rule (11 km) | 11 |

The 263 the floor saves are parked jitter, not data. ⚠️ **That measurement is now load-bearing twice over**: `src/gps/fix-plausibility.ts`'s `MAX_STEP_METRES` is a floor of the same size, derived independently from the cost curve in `docs/waypoints.md` and **not** a shared constant — this one is a despiker threshold in squared degrees over per-second points, that one a great-circle distance between two live fixes, and they are free to move apart. The agreement matters in the other direction: because this floor defines what counts as an excursion, it also bounds what the archive can say about any waypoint threshold below ~130 m. The 17 it keeps are a strict superset of what the old absolute rule caught, and the 6 it adds are unambiguous: every one is an out-and-back whose outbound and return legs agree to within metres while the neighbours sit metres apart — the smallest being 284 m out and 280 m back in 1.6 s, or 640 km/h. 220 m is far above GPS jitter and far below any real excursion.

Distances stay **squared and in degrees**: no `SQRT`, no `POW`, no trig, so nothing depends on the datasource's SQLite being built with `SQLITE_ENABLE_MATH_FUNCTIONS`.

> ⚠️ An earlier version gated on the time step instead — skip the test when `dt > 120 s`, on the grounds that a long gap can legitimately move a long way. That let exactly **two** corrupt fixes through, both in stretches where reception was sparse enough that the neighbouring steps exceeded the gate. Two points out of 67 851 were enough to stretch the map's auto-fit to the whole globe. **A despiker on map data is not judged by the fraction it catches but by whether any survive.**

### Both window edges need slack, not just the lower one

The spike test needs a point on each side, so a point with no successor is never tested — and with a window bounded at `$__to`, that is **the last point of every window**. Since the dashboard's default range ends at `now`, the untested point is the newest fix in the archive.

Measured before the fix: setting `$__to` to one of the archive's corrupt longitudes returned a window whose final point sat ~120° from the track, and one window returned a **single row**, the corrupt fix itself. `fit` then framed half the planet — precisely the failure this section says the despiker exists to prevent, reintroduced at the boundary.

So `raw` reaches 10 minutes past `$__to` as well as below `$__from`, and `budgeted` trims back to the window afterwards. The genuinely last point in the database still has no successor; that is one point at the end of all data rather than one at the end of every view.

⚠️ **Since [Materialised once, not per load](#materialised-once-not-per-load) the build has no window at all**, so this is no longer something a view can get wrong: the despiker runs over the whole archive and the only two untested points are its first and its last. The measurement above is kept because it is why the rule exists — any future query that re-introduces a window inherits the same failure, and this is the record of what it costs.

## Charge sessions need slack at the window edges too

Same shape of bug, different query. The evidence stream was bounded at the window, so a session straddling `$__from` was **clipped rather than excluded**, and clipping is the worse failure: the session kept rendering, with the window's own `from` as its start time and a third of its energy missing, and nothing on screen said so. Opening the window later still made it vanish outright, because the clipped span fell under the five-minute minimum — which also silently removed the ride split that session was supposed to cause.

The evidence now reaches 12 hours either side and sessions are kept on **overlap** with the window. A session reports the same start time and the same energy from any window that contains any part of it.

## The track is points, not a line

This is a correctness decision, not a style one.

Grafana's route layer joins every point in the frame in order, so a window spanning more than one ride draws a straight line from the end of one to the start of the next. On this data that is a clean green line running most of the way across Europe, down roads the bike was on a trailer for. It looks exactly like a ride.

**There is no way to break that line.** The layer's `update` is, in full:

```js
update: (data) => {
  if (data.series?.length)
    for (const frame of data.series) { ...; updateLineString(frame); break; }
}
```

It renders `series[0]` and nothing else. So the obvious fix — split the query into one frame per segment with a `partitionByValues` transformation — draws only the _first_ segment and silently discards the rest.

The other obvious fix, emitting `NULL` coordinate rows as break markers, is worse than useless: a `NULL` coordinate makes the layer's extent `NaN`, and _"fit to data"_ then falls back to centre 0,0 / zoom 1 — an empty world map, with nothing logged anywhere. It takes the charge-stop markers down with it at the same time.

A markers layer has none of these problems: it cannot fabricate a path, and where the bike was not logging the points simply stop. At 1 Hz they read as a continuous track anyway.

### Thinning

Every point is an individually styled OpenLayers feature. At the archive's full ~68 000 the layer **stops painting altogether** — tiles load, the canvas stays black, nothing is logged to the console. 12 000 renders comfortably, so the query thins to that budget. (⚠️ That ~68 000 was both the archive's size and the size at which painting stopped, on the 2026-09-07 decrypt. The archive is **146 150** points as of 2026-09-12, so it is now well past that ceiling and the thinning is the only reason the layer paints at all. The ceiling itself has not been re-measured.)

The stride is derived from the window's own row count, which makes it self-correcting: zoom out to 90 days and points land ~6 s apart (sub-pixel at that scale); narrow to one ride and the stride falls back to 1 and every fix is drawn.

> Use **ceiling** division. Plain `total / 12000` is integer division in SQLite, so a 23 616-point ride day gives a stride of 1 and no thinning at all — twice the budget, and the failure is silent.

## `view.zoom` is the fit's zoom cap, and it must be set

Setting the panel's initial view to _"Fit to data"_ is not enough. Geomap computes the cap as:

```js
const cap = view.zoom ?? view.maxZoom;
view.fit(extent, { maxZoom: cap });
if (currentZoom > cap) view.setZoom(cap);
```

The panel's **default view object supplies `zoom: 1`**, so an unset `zoom` pins every fit to zoom level 1 — the whole world — and `maxZoom` is never consulted at all. Measured on 11.3.0: the map loaded centred on 0,0 at zoom 1 with `maxZoom: 18` set and ignored, and the panel editor's "Max Zoom" field read `1` while the JSON said `18`.

So `view.zoom` is set to 18. Because `id` is `fit`, geomap's final `if (view.zoom && id !== Fit) setZoom(view.zoom)` does not fire, and it acts purely as the cap.

## A charge stop is not a measured position

**This bike logs almost no GPS while charging.** The Connectivity Hub sleeps, so of the 20 sessions the current detector finds across the archive, **11 contain no GPS fix at all** — and of the 51 `charger_enabled` rising edges, most are handshakes lasting seconds, which is why sessions are built from current rather than from that flag.

A charge stop is therefore drawn at the **last fix from before the bike was plugged in**, and that fix's age ranges from seconds to over a week (the worst in the archive is 14 122 minutes — nearly ten days). Two sessions have no prior fix at all, because GPS logging started later that same evening; they are listed in the table but cannot be drawn.

`Fix age (min)` is carried as a field and drives the marker colour — green under 30 minutes, amber past that, red past six hours — so a stale position is visible as stale rather than drawn as a confident pin. This is the same argument `public/lib/bounds.js` makes for readings: a value that cannot be trusted is shown as a fault, never quietly rendered as something plausible. (That file gates no coordinate — `gps_lat` and `gps_lon` have no entry in it — so the principle is borrowed, not the mechanism. Nothing upstream of this dashboard filters a position.)

### The inherited fix has to be one nothing contradicts

The lookup takes the newest row at or before plug-in, and **that is the one row a despiker can never see**: a lone excursion is only ever visible from its neighbours, and `r.ts <= sess.start_ts` forbids looking at the one that comes after. A corrupt final fix therefore sat there as the newest row for the whole session, and because all three layers share one `options.view` of `fit` with `allLayers: true`, one pin on another continent reframed the whole map — verbatim the failure [Despiking by shape](#despiking-by-shape-not-by-speed-and-not-by-coordinate-range) exists to prevent (#173).

So each of the three GPS sub-selects carries a clause refusing a row that a same-axis row **within ±2 s of it, in the same run**, disagrees with by more than 0.002°. `ORDER BY r.ts DESC LIMIT 1` then walks back to the newest row nothing contradicts. No window functions, no per-second pivot, no `clean` CTE duplicated into four targets.

**The two constants:**

- **±2 000 ms** — 3.03× the measured maximum lifetime of an excursion (661 ms; `docs/waypoints.md` §"The first fix of a run" has the derivation), and short enough that the bike cannot cross the threshold **in latitude** inside it: 300 km/h for 2 s is 167 m against 222.6 m. ⚠️ Not a guarantee in longitude — the next bullet has the threshold as tight as 118 m there.
- **0.002°** — 222 m in latitude, and 118–182 m in longitude across the 35–58°N this archive spans. Above the 220 m floor the track's despiker already derives; below the smallest measured excursion, 227 m. ⚠️ The longitude figure is the tight end, and a genuinely fast pair with a 2 s row gap would be called contradicted and step back a row — **up to ~180 m**, not the ~40 m an earlier draft claimed. That is affordable _here_ and would not be in `src/gps/waypoint.ts`: a false positive costs metres of pin on a position whose staleness is already reported in minutes, not a place the rider loses.

**Both directions are load-bearing.** Forward catches an excursion whose correction is logged; backward catches one the receiver never corrected because it fell silent — which is the mechanism the issue describes. A refinement of "backward **AND** (forward **OR** no successor)" was tried and refuted by the archive: it catches **5 of 13** independent ≥1 000 km excursions and **moves a charge pin by 271 km**, because an excursion after a > 2 s gap has no backward witness and one before silence has no forward witness. The `OR` across the two arms is what makes it work.

⚠️ **`IS`, never `=`, on the session** — and the failure direction is the point. The predicate sits inside `NOT EXISTS`, so an unknown comparison selects nothing, `NOT EXISTS` is satisfied, and the row is **never marked**. `=` does not over-reject the 110 654 GPS rows that carry no session; it **switches the gate off** over them, silently, with nothing in the query plan to say so. Measured: 57 `gps_lat` and 57 `gps_lon` rows marked in that block under `IS`, **0 and 0** under `=` — and the 2026-08-09 corrupt longitude, the row this exists for, is contradicted under `IS` and not under `=`.

And the session predicate is needed at all because `ts` is wall clock the Pi steps: without it, rows from two runs written days and hundreds of km apart contradict each other, and **26 `gps_lat` and 29 `gps_lon` real fixes** are rejected across the archive.

**What it costs, measured over the whole archive:**

| | |
| --- | --- |
| independent ≥ 1 000 km excursions caught | 13 of 13 |
| all shape-test excursions caught | 65 of 65 |
| `gps_lat` / `gps_lon` rows marked | 189 (0.099 %) / 237 (0.116 %) |
| charge sessions whose inherited row changes | **1 of 29** |
| that pin's move | 0.9 m, and its `Fix age` 13.9 → 14.4 min |
| target G over the whole archive | 0.30 s, against the shipped query's 0.30 s |

The one row that changes is not a save: it falls back from the **correction row** immediately after a 2.442° latitude excursion to the row before that excursion. Near a known excursion the lookup steps to a row with nothing anomalous inside its own window, which is the "up to two rows back" cost.

⚠️ `lat` and `lon` are resolved by **independent** sub-selects, so a gated axis can step back while the other does not, and `fix_ts` follows `lat` only. That was already true; the clause makes it visible.

**The residual, stated:** an excursion that is _both_ the first fix after a gap longer than 2 s _and_ the last before silence has no witness on either side. It is the same shape as the first-fix hole in `docs/waypoints.md`, and it is not closable from one row.

### ⚠️ The skew that was measured and not taken

The obvious fix — take the last fix at least ~5 s before `start_ts`, the way #167's waypoint gate skews its witness — **does not reduce the hazard**, and the measurement is worth keeping so it is not proposed again.

The newest row before _any_ fixed cutoff is an excursion exactly when the cutoff falls in the band between an excursion and its correction. Moving the cutoff 5 s earlier does not remove that band, it moves it — and the correction that would have exposed the excursion is then _also_ after the cutoff, and _also_ excluded. Three measurements say the same thing:

- **20 of the 27 placeable sessions inherit a row already older than 5 s** (10 s to 847 337 s — nearly ten days), so a 5 s shift reaches nothing at all for two thirds of the archive. Only 7 sessions have a last fix inside 5 s.
- For those 7 it costs **1.9, 19.8, 21.5, 32.5, 36.6, 88.6 and 156.3 m** of pin position, for no change in exposure.
- The premise that plug-in is a special moment is not supported: excursions within ±120 s of the 29 session starts, **0 observed against 1.400 expected**; at ±600 s, 3 against 6.999. ⚠️ That test refutes nothing on its own — P(0 | 1.4) = 0.247 — **and it is the wrong test**: it measures _clustering_, while the issue argued _persistence_, that an excursion near plug-in is more likely to have no successor and so stay the newest row. The clause above makes that moot rather than untested, because it does not depend on a successor existing.

The defect was never where the cutoff sits. It was that the query only ever looked backwards, while the hub keeps logging past plug-in: in all seven sessions whose last fix is within 1.2 s of `start_ts`, there is another fix **0.1–2.6 s after** it.

## Charge sessions are built from evidence that current flowed

Not from `charger_enabled`. That flag is log-on-change and **stays at 1 for days after the bike sleeps mid-session**: it merged a 2026-08-04 charge and a 2026-08-07 charge into a single three-day "session", with nothing in between but an unchanged flag. Sessions are instead runs of rows where a charging current is actually non-zero, merged across breaks under 30 minutes and kept past 5 minutes.

### `fast_dc_target_a` is the DC current — `dc_a` is not

🚨 **The single most consequential thing on this page.** A DC session sends no `0x305`/`0x306` at all, so `fast_dc_target_a` is the only DC-side current on the bus (see `docs/charge-manager.md`). `dc_a` is **not** that signal — it is present through AC charging too, reaching 6.7 A on a day whose DC legs pulled 73 A.

Detecting on `mains_a`/`dc_a` alone found **2 stops and 500 Wh** across a 498 km touring day, silently missing every fast charge that made the day possible. With `fast_dc_target_a` in the evidence set the same day reads:

| started (UTC) | min | type | kWh | SOC |
| --- | --- | ---- | ----- | --- |
| 10:59 | 64  | AC | 0.34  | 97 → 99 |
| 16:06 | 52  | DC | 9.06  | 32 → 85 |
| 18:28 | 68  | DC | 11.64 | 21 → 91 |
| 22:50 | 21  | DC | 6.34  | 27 → 66 |
| 00:08 | 16  | AC | 0.16  | 18 → 19 |

The AC/DC verdict rests on `fast_dc_target_a` for the same reason. `charge_type` (`1` = AC, `2` = DC) agrees where it exists but is far too sparse to key on — **23 rows in the entire archive, 4 of them on the ride day** — and it needs seeding from before the window opens, since the value in force at a ride's start was typically last written days earlier.

Energy is the pack's own `residual_energy_wh` at the end of a session minus its value at the start, each carried forward from before its bound rather than read inside it.

## No coordinates anywhere

Not in the dashboard JSON, not in the SQL, not in this file. Three places wanted one:

- the map's initial view — solved by `fit` (plus the `view.zoom` cap above) rather than a saved centre/zoom, so the panel derives its own view from whatever data is in the window;
- the despiker — solved by the shape test above rather than a `BETWEEN` on latitude/longitude;
- the "Distance" tile — reads the bike's own `odometer_can_km` delta, which is exact, needs no `SQRT`, and says nothing about where.

**The waypoint gate does put a `BETWEEN` on latitude and longitude, and it is not an exception to this.** `±90` and `±180` are the planet, not a region: they say a coordinate is a coordinate, and they would read identically in a repository belonging to a bike on another continent. The part of that gate which actually catches a wrong position is a _comparison against the fixes either side of it_ — a difference, never a place. See [Waypoints](#waypoints-are-gated-against-the-track-not-against-a-box) below and `docs/waypoints.md`.

## Waypoints are gated against the track, not against a box

A waypoint (`waypoint_seq`, `waypoint_lat`, `waypoint_lon`) is a copy of the live GPS fix, taken when the rider asks — from the handlebar, the phone's button or Siri. The map draws the corroborated ones as stars and the table below it lists every one in the window with a verdict, including the ones the map refuses.

The gate, and the two constants behind it, are derived in `docs/waypoints.md`. The one thing worth repeating here, because it is the same mistake this file's despiker section warns about from the other direction: **the fix logged immediately before a waypoint is the fix the waypoint copied**, so comparing the two proves nothing. `gps_lat`/`gps_lon` carry a 3 m deadband and a waypoint copies liveState, so the two are equal by construction — on 2026-08-09 the previous `gps_lon` row is byte-identical to the waypoint 148 ms later, and _that row was the corrupt one_. The witness has to be at least five seconds away before it is evidence at all.

Two things the waypoint query does differently from the track query above, both for reasons that do not apply to the track:

- it is driven by `waypoint_seq` and resolves each coordinate as "the last value logged at or before this timestamp", rather than pivoting the three signals on their shared `ts`. They do share one — `record()` stamps all three with a single `now` — but `waypoint_lat`/`waypoint_lon` carry no deadband, so a second save from the same live fix logs _only_ the sequence, and a pivot would hand the map a `NULL` position and the table an accusation. The carried value is exact rather than approximate: suppression happens only when the two values are equal.
- its despiking is a fixed 0.5°, not the track's scale-free ratio. The witness set only has to be free of excursions big enough to matter at the threshold it is compared against; the track's job is to catch _all_ of them, which is why it cannot use a fixed distance.

## A charge stop ends a ride

The Rides table splits on charging, not only on GPS gaps. Before that rule the evening of 2026-09-07 read as **one 281-minute, 217 km ride** — with a 21-minute DC stop sitting inside it and its duration counted as riding time. It is really two rides:

| | minutes | km |
| --- | --- | ----- |
| before the DC stop | 193 | 132.8 |
| after it | 56 | 83.9  |

Distance is conserved (132.8 + 83.9 ≈ 217); what disappears is the half hour the bike spent plugged in and stationary.

Two things enforce it. Fixes logged **while plugged in are dropped outright** — a stationary hour at a charger is not riding, and on the sessions where the hub does stay awake it would otherwise open the next ride with a long motionless prefix. And a session **starting between two surviving fixes forces a break**, which is what catches short stops: a 21-minute charge leaves no 30-minute hole for the gap rule to find.

## What the tiles count, and what the map can draw

The "Charge stops" and "Energy charged" tiles count **every** session, including the ones with no known position. The map necessarily draws only those it can place. Those two numbers therefore differ — 20 against 18 pins over the default range — and the tiles are the honest answer to "how much did it charge", so they are the ones that count everything.

An earlier version built the tiles by wrapping the _map_ query, which inherited its `lat IS NOT NULL` filter. The tiles then silently under-reported by exactly the sessions the panel description calls out as unplaceable — a tile labelled "Charge stops" reporting mappable charge stops, with nothing to say so.

## Known limitations

- **Rides are runs of GPS fixes**, not of motion, so a stretch with no reception splits one ride in two. `km` comes from the odometer rather than from the fixes, so the distance stays right even where the track does not.
- **Why those stretches exist, and what could fill them, is `docs/gps-gaps.md`.** Short version: 330 hours of apparent holes carry 0.0 km, position has been on CAN `0x410` since #22 so a BLE drop-out costs none of it, and only ~10 % of the genuinely dark distance had a fix on the bus that never reached the log.
- Sessions shorter than 5 minutes, and charging under 0.5 A, are not counted as stops — and a ride that straddles one of those is not split by it.
- **`Type` is three-valued.** `fast_dc_target_a` does not exist before 2026-08-26, so a session older than that cannot be shown to be DC. It reads `AC` only where mains current positively says so and `?` otherwise; it is never inferred from the absence of the DC signal.
- **The Charging dashboard is built on the AC charger's frames**, which a DC session does not send, so most of its panels come back empty for a DC stop. The `Started` cell therefore offers two links — Charging for AC, Charge manager for DC — rather than guessing.
- Rides are split by _detected_ charge sessions, so the same 5-minute floor applies: a shorter stop will not split a ride.
- **`gps_speed_kmh` is gated to `public/lib/bounds.js`'s declared 0…300 range**, which is the right gate: this bike's top speed is 270 km/h, so a "Top km/h" of 256 is a real reading and not an artefact. (An earlier draft of this document called that value implausible and proposed tightening the bound. It was wrong about the bike.)
- The 49 772 readings stamped 2060 (a corrupt GPS frame stepped the Pi's clock; see the Clock section of `README.md`) are excluded by an explicit `ts < 2000000000000` guard in every query, **and** by the dashboard defaulting to a relative `now-90d → now` range: `now` is before 2060, so those rows sort after the window and fall out on their own. A hardcoded absolute range would work today and go stale; the relative one stays correct as new rides land.

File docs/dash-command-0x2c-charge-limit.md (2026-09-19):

# Dash command `0x2C` — the SOC charge limit ("stop charging at N %")

The bike's own charge limit, on the non-diagnostic VCU command channel described in [dash-command-channel.md](dash-command-channel.md). Request on `0x120`, reply on `0x121`; b0 is a 7-bit command id plus bit 7 (**set = write, clear = read**), b1 is the `0xFF` separator, b2 is the percentage 1:1, and **0 means no limit**.

⚠️ Write `0x2C` as _dash command `0x2C`_, never as a bare `0x2C`: on this bus `0x02C` is `DRIVE_TORQUE_CAN_ID` (`src/can/drive.ts`) and `0x2C` is also a KWP service. Three meanings, one string.

Read and written on-bike 2026-09-19: **80 → 90 %**, read back twice from the VCU's own store.

## What the frames are

| what | id | bytes |
| --- | --- | --- |
| read | `0x120` | `2C FF 00 00 00 00 00 00` |
| write N % | `0x120` | `AC FF <N> 00 00 00 00 00` (`0xAC = 0x2C \| 0x80`) |
| the VCU's reply | `0x121` | `2C FF <stored> 00 00 00 00 00` |

`src/can/charge-soc-command.ts` builds the two requests, `src/can/charge-soc-limit.ts` decodes the reply into `charge_soc_limit_pct`, and `src/vcu/charge-soc-limit.ts` is the round trip.

## The encoding, from the bike's own menu

Three `0x2C` events exist in the whole local capture archive, all of them the rider confirming the bike's own menu item, and they are what the percentage reading rests on:

```
2026-08-02 21:02:15.795230  120  AC FF 28 …   ← 40 %, while SOC read 39 % on a live 1 A AC charge
2026-09-19 16:56:23.061347  120  AC FF 00 …   ← 0 (no limit): the value the menu stood at
2026-09-19 16:56:31.189895  120  AC FF 50 …   ← 80 %
```

The 2026-08-02 one is the best of the three: `0x200` b1 read `0x27` = 39 % at that instant, so the rider was setting the limit one point above where the pack already was. `docs/can-decode-findings.md` also records a `0x2C` carrying b2 = `0x4B` = 75, from a capture not in the local archive.

**It is emitted on the menu's confirm, not on the scroll.** Between the two 2026-09-19 frames there are **ten button presses** on `0x102` b0 bits 0/1/2 — 4 left, 2 right, 4 enter — and only the last enter produced a frame, 1.474 ms later (the first frame followed its enter by 3.506 ms). So three of those four enters put nothing on this channel: enter is necessary, not sufficient.

**Nothing broadcasts the limit.** Scanning 16:54:31–16:58:31 across `capture-20260919-165030-…` and `capture-20260919-165614-…` — 74 ids, 585 (id, byte) positions — the only position that is constant before the change and constant-but-different after is `0x121` b2 itself. Byte-aligned only: a limit carried in a nibble, scaled, or multiplexed would not show.

## The read is the VCU's stored value, not an echo

The request carries `b2 = 0` and the reply comes back with the stored percentage, so the reply cannot be a reflection of what was asked. Measured twice over: the 2026-08-27 sweep asked `0x18` with b2 = 0 and was answered 60, and on 2026-09-19 a `2C FF 00` request was answered `2C FF 50`.

**Reads do not mutate.** Two reads a second apart on 2026-09-19 both returned 80, either side of nothing. That matters because the archive leaves a gap — the limit read 40 on 2026-08-02 and 0 at the 2026-08-27 sweep — and "the sweep's own read zeroed it" was a live explanation until this test. It is now dead for `0x2C`; the rider having cleared it in those 25 days is what is left.

⚠️ The non-mutating claim for the _other_ 127 ids is still second-hand. It comes from `scripts/dash-command-sweep.ts`, which credits a third-party document that is not on this machine. Nobody in this chain has read it.

## The reply carries no min/max

`0x18` answers `3c 01 4b`, which reads equally well as _value 60, min 1, max 75_ or as _value, limit-in-force, ceiling_ — the repo says both, in [dash-command-channel.md](dash-command-channel.md) and `src/can/charge-setpoint.ts`, and **the archive cannot separate them**: all 105 archived current-limit replies carry `b3 = 0x01`, which both readings predict.

`0x2C` needs no answer to that question. Its replies are `2C FF <pct> 00 00 00 00 00` — b3 through b7 zero in **all ten observations**: the three archived dash frames, and the seven replies of 2026-09-19 (six answers to bit-7-clear reads, plus the bike's answer to the write). So it states no range at all, and the control is bounded by a declared 0–100 rather than by anything the bike says.

## One frame, not the pair — the `0x121` is the bike's answer

The archived events look like pairs, `0x120` then `0x121` a few ms later. **They are not two halves of a command.** On 2026-09-19 this Pi sent the `0x120` write _alone_ and the capture shows a `0x121` appearing 7.66 ms later that nothing on the Pi transmitted:

```
22:53:07.893493  120  2C FF 00 …   ← the read-before
22:53:07.895079  121  2C FF 50 …   ←   answered in 1.59 ms: still 80
22:53:07.900690  120  AC FF 5A …   ← the write, and the ONLY frame we sent for it
22:53:07.908354  121  2C FF 5A …   ←   the BIKE's answer, 7.66 ms later — we sent no 0x121
22:53:07.941532  120  2C FF 00 …   ← the read-back
22:53:07.944784  121  2C FF 5A …   ←   answered in 3.25 ms: 90
```

So `0x120` carries every request and `0x121` carries every reply, and injecting a `0x121` would spoof a VCU→dash reply rather than complete a command. That is exactly the mechanism behind [can-0x121-charge-command.md](can-0x121-charge-command.md)'s "the display moved and the setpoint did not", and it is why `buildChargeSocLimitWrite` returns one frame.

⚠️ **This corrects a shipped comment.** `scripts/dash-command-write.ts` said _"the VCU emits no 0x121 ack for an injected 0x120 write"_. It does — 7.66 ms later, byte for byte the value written. The 2026-09-09 finding in [can-0x121-charge-command.md](can-0x121-charge-command.md) was right and that comment was wrong.

### Reply latency, and where the slow first read actually was

The bike answers in **1.310–7.664 ms**, mean 3.672 — the seven exchanges of 2026-09-19, measured request-to-reply off the capture: 5.543, 3.319, 1.586, 7.664, 3.252, 1.310, 3.033 ms. Never slow, and straddling the 4.217–10.122 ms window the dash's own exchanges occupy. The probe that reported a "99 ms cold read" was measuring **its own send path**: it stamped 20:52:04.528Z before `channel.send`, and the kernel put the frame on the wire at 22:52:04.611064 CEST — 83 ms later, on a Pi Zero 2 W with a cold code path. The bike then answered in 5.54 ms. Measure this channel's latency from the capture, not from the sender.

## What is proven, and what is not

✅ The VCU **stores** the value. Written 90, read back 90 by two independent programs, the second 18 s later — well past the 40 ms settle, so not a pending display value.

❌ That the bike **stops** at that percentage is **not proven**, and nothing in this repo has ever observed the limit being reached: the 2026-08-02 capture ends **6.125 s** after SOC reached its 40 % limit (39 → 40 at 21:07:52.970126, the last `0x300` still `charger_enabled = 1` at 21:07:59.095608) and the following capture is a different boot with a stepped clock. Only a charge that gets there settles it. Every message the dashboard shows says so rather than implying a guarantee.

## The signal, and its three sources

`charge_soc_limit_pct` (`src/can/registry.ts`, bounds 0–100) is an **event**, like `dc_charge_limit_selected_a` beside it — nothing rebroadcasts it, so an absent value means "not asked and not touched", never "no limit". It arrives from **three** sources, and the third is the one that has bitten this repo before (`src/charge/auto.ts`, #186):

1. the rider confirming the menu item on the bike,
2. this Pi reading it,
3. **the bike answering this Pi's own write**, ~6 ms later.

Nothing in the first version consumes it as rider intent, so the third is harmless here — but it is written down because the next reader may want to.

## Gating

`charge-soc-limit` and `charge-soc-limit-read` take the **bike-state gate** (`serviceActionPolicy` in `src/vcu/write-runner.ts`), unlike charge-current and charge-stop, which are exempt. The exemption exists because an automatic controller issues charge-current mid-charge and a flapping refusal would break its loop; these two are one-off human presses, where a transient refusal costs a second press. And the gate is the coverage they want: `scripts/check-service-gate-charging.ts` has it passing a stationary bike with the **drive down**, unplugged, and a stationary AC-charging one, and refusing while the bike moves — which the exemption would not. ⚠️ A stationary but ENERGIZED bike with the drive up is refused too, so "unplugged" alone overstates it.

The limit is a **stored** setting. Dash-command writes persist past the sender exiting, and the 80 % set at 16:56 was still in force hours later, so "unplug and it forgets" — charge-current's safety floor — is not available here. What is available, and what no other write action has, is the read-back. That is the argument for it being confirmed-and-reversible rather than behind the red fold; it is written out beside `REVERSIBLE_CONFIRMED` in `scripts/check-irreversible-actions.ts`.

Writing **0** removes the battery protection rather than moving it, so it needs its own confirm token (`confirm=charge-soc-limit-off`) and never the numeric path.

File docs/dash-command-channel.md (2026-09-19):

# The VCU dashboard command channel (0x120/0x121) — on-bike id map

The `0x120`/`0x121` pair is the non-diagnostic command channel: we transmit a request on `0x120` (`VCU_COMMAND_REQ`), the VCU answers on `0x121` (`VCU_COMMAND_RES`). It already carries the RTC clock (`0x14`, written by cool-eva), charge-stop (`0x16`), and charge-current (`0x18`/`0x1A`). Frame byte 0 is a 7-bit command id plus bit 7 (set = write, clear = read); byte 1 is the `0xFF` separator; bytes 2.. are the payload.

This channel matters to the headlight hunt because it is **injectable without a diagnostic session** — no `0x10`/`0x27` handshake, unlike the `0x2F` route in [headlight-diagnostic-control.md](headlight-diagnostic-control.md). If a general beam control existed here, turning the light off would not need the safety-node unlock.

## The sweep — this Eva Ribelle, 2026-08-27

Read-only sweep of all 128 ids (`scripts/dash-command-sweep.ts`, bit 7 always clear — documented non-mutating), key on, headlight on, not charging, service stopped. **19 live, 109 unsupported, 0 silent** — the same live count the service-tool analysis found on an SS9.

| id | reply bytes | meaning |
| --- | --- | --- |
| `0x01` | `01 ff 9d 02 03 00` | Ride map |
| `0x02` | `03 ff 9d 02 03 00` | Regen map |
| `0x04` | `02 03 00 …` | unlabelled |
| `0x05` | `00 …` | unlabelled |
| `0x06` | `00 …` | unlabelled |
| `0x15` | `00 …` | **LPR mode (0=off/1=on)** — reads 0 |
| `0x17` | `64 …` | unlabelled (`0x64` = 100 — looks like a %) |
| `0x18` | `3c 01 4b …` | DC charge current (value 60, min 1, max 75) |
| `0x1A` | `01 01 0f …` | AC charge current (value 1, min 1, max 15) |
| `0x1B` | `55 …` | unlabelled (`0x55` = 85) |
| `0x1C` | `55 …` | unlabelled (`0x55` = 85) |
| `0x1F` | `62 02 0f …` | unlabelled |
| `0x20` | `ff 9d …` | unlabelled |
| `0x2A` | `00 …` | **Light in charge (0=off/1=on)** — reads 0 |
| `0x2B` | `00 …` | Fan limit % (30-100) |
| `0x2C` | `00 …` | **Charge limit %** (0 = no limit) — read and written on-bike 2026-09-19, [dash-command-0x2c-charge-limit.md](dash-command-0x2c-charge-limit.md) |
| `0x2D` | `00 …` | unlabelled |
| `0x2E` | `00 …` | unlabelled |
| `0x7E` | `0f 2c …` | unlabelled |

## Verdict for the headlight hunt

**No general "headlight on/off" command exists on this channel.** The only two light-labelled ids are both live but neither is a beam switch:

- **`0x2A` "Light in charge"** reads `0`. This is a _charge-scoped setting_ — whether the headlight stays on while a charger is plugged in — not a general switch. It already reads 0 (light off during charge), and writing it would only change charge-time behaviour, not the beam while riding. This is the CAN-visible cousin of the physical charge interlock in [headlight-charge-interlock.md](headlight-charge-interlock.md), not a replacement for it.
- **`0x15` "LPR mode"** — **write-tested on-bike 2026-08-27, and it is NOT a light.** Writing `0x15 = 1` makes the dash read "LPR mode active" (confirmed from a known `0`→`1`), and `= 0` clears it; no beam, lamp, or DRL moved either way. So it is a genuine, working non-diagnostic dash toggle — just not the one we want. "LPR" has **no expansion anywhere** in the vendor tool; its ordering near the light/charge cluster was a red herring. Tooling: `scripts/lpr-mode.ts` (`--on`/`--off`/read). The write is a _stored setting_ — it persisted across the script exiting, unlike the `0x2F` diagnostic force that decays in <40 ms.

None of the 11 unlabelled live ids looks like a beam control; their values read as config/percentages (`0x17`=100, `0x1B`/`0x1C`=85). **Caution:** these dash ids collide numerically with the `0xA9` calibration/parameter table (e.g. param `0x1C` = "charger fan on temp") — that is a _different address space_, and the collision is coincidence, not a label for the dash command. Do not import those meanings here.

## What's left on CAN — nothing _non-diagnostic_. But the diagnostic side has two routes.

The write probe is done. `0x15` was the last candidate, and it drives LPR mode, not a light (above). `0x2A` is charge-scoped. No unlabelled id looks light-like. There is **no non-diagnostic CAN control for the headlight** on this bike.

⚠️ **This is a verdict about the _non-diagnostic_ channel only — do not read it as "the headlight can't be switched off."** Two diagnostic routes are now confirmed on-bike, both behind the `0x10`/`0x27` VCU-Safety session:

1. **io_set force** (`0x2F` control 17 → 0) — immediate but decays in <40 ms, so it needs a ~5 ms re-assert to hold ([headlight-diagnostic-control.md](headlight-diagnostic-control.md)).
2. **Beam current-threshold write** (`0x2E` `BEAM_MAX_CURR_TH` below the real draw) — **persistent** across power cycles, takes effect at the next beam init with a `B1012`/`B1009` open-circuit DTC ([headlight-beam-threshold.md](headlight-beam-threshold.md)). This is what a rider means by "turned the headlight off and it complained about low circuit amps."

What the probe _did_ establish, worth keeping: **dash-command writes work by injection and are the same class cool-eva already ships** (RTC `0x14`, charge `0x16`/`0x18`/`0x1A`) — b0 = `id | 0x80`, b1 = `0xFF`, b2 = value, on `0x120` alone, **no diagnostic session**, and the value is _stored_ (persists across the sender exiting). This does **not** cross the `0x2F`/`0x27` ban. The service-tool analysis had left these writes untested; `scripts/dash-command-write.ts` (guarded to the light-labelled ids unless `--force-id`) and `scripts/lpr-mode.ts` are the first live writes of a non-charge dash id.

So the only confirmed headlight-off is still the diagnostic `0x2F` route ([headlight-diagnostic-control.md](headlight-diagnostic-control.md)). A true no-diagnostic, works-while-riding "off" now points at hardware — a tap on the low-beam switch _input_ line (cleaner than cutting lamp power, which the VCU current-senses and would fault on).

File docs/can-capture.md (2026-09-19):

# The raw CAN capture, and why the service stopped bouncing `can0`

The Pi runs a `candump` alongside the service, writing every frame on `can0` to `/home/pi/ride-captures/`. That corpus is the evidence base for essentially every decode finding in this repo — `docs/can-decode-findings.md`, the ABS work, the charge-manager reconstruction, the 29 freeze-frame replies. It is also the only record that cannot be regenerated: a frame not captured is gone.

This file is why the service used to punch a hole in it on every deploy, what changed, and what a hole still looks like.

> ⚠️ **Calibration.** Nearly everything below cites kernel, iproute2, systemd or can-utils source, and several of those citations were wrong at some point in this file's short life — mostly because they were relayed from a review comment and repeated without anyone opening the file, and once because a fetch was asked to _characterise_ code rather than quote it and answered confidently backwards, overwriting a true sentence. Fetching and reading is what fixed them. `CLAUDE.md` carries the rule; this note is here because it is this file that earned it. Treat a citation you have not opened as a lead.

## The mechanism, measured twice

`bringUpCan()` took `can0` **down** before bringing it up, on every service start. `ip link set can0 down` ends the `candump` behind `can-capture.service`, whose unit carries `Restart=on-failure` / `RestartSec=5` — ⚠️ quoted from issue #160, not read here: the unit and `capture.sh` are tracked nowhere in this repo and PR 2 gathers them — so systemd waited five seconds and `capture.sh` opened a **new file**. The two gaps below were measured; the directives explaining them were not.

| path | gap | evidence |
| --- | --- | --- |
| the documented freeze-frame procedure | **5 s**, 13:18:44 → 13:18:49 | `capture-20260908-131849-db6cbfba.log`; components 51 and 52 completed inside the hole and were never captured |
| a routine deploy, `dd8acac` → `16a7282` | **~6 s**, 15:08:48 → 15:08:54 | `capture-20260908-150854-59eceef8.log`, two `can-capture` restart events in the window |
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

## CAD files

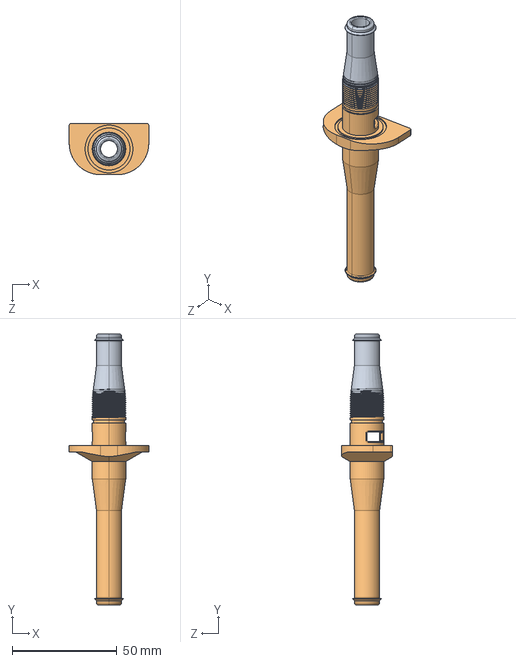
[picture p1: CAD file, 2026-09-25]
cad/C-3P3W827551A_TransferOutlet2.STEP
38.0 x 129.2 x 24.5 mm

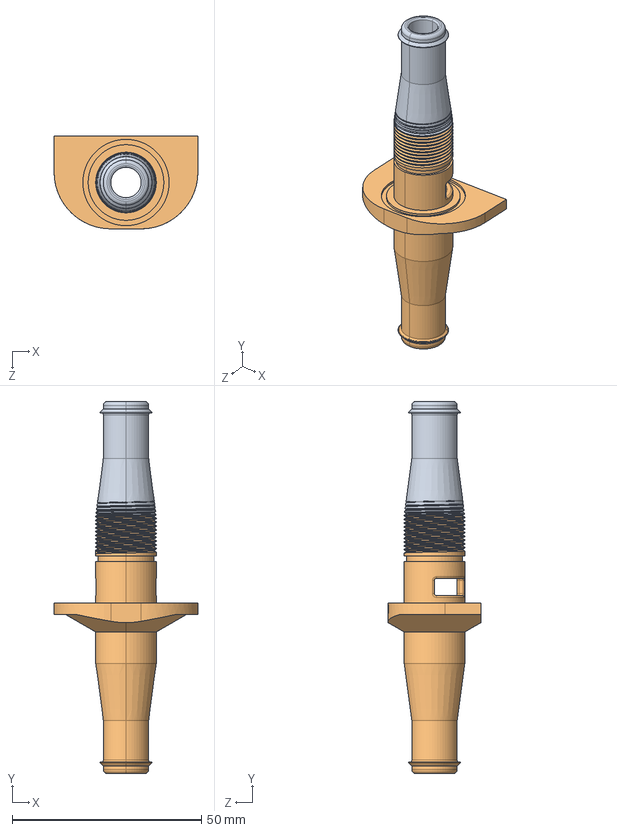
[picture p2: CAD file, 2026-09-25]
cad/C-3P3W827551A_TransferInlet2.STEP
38.0 x 98.2 x 24.5 mm

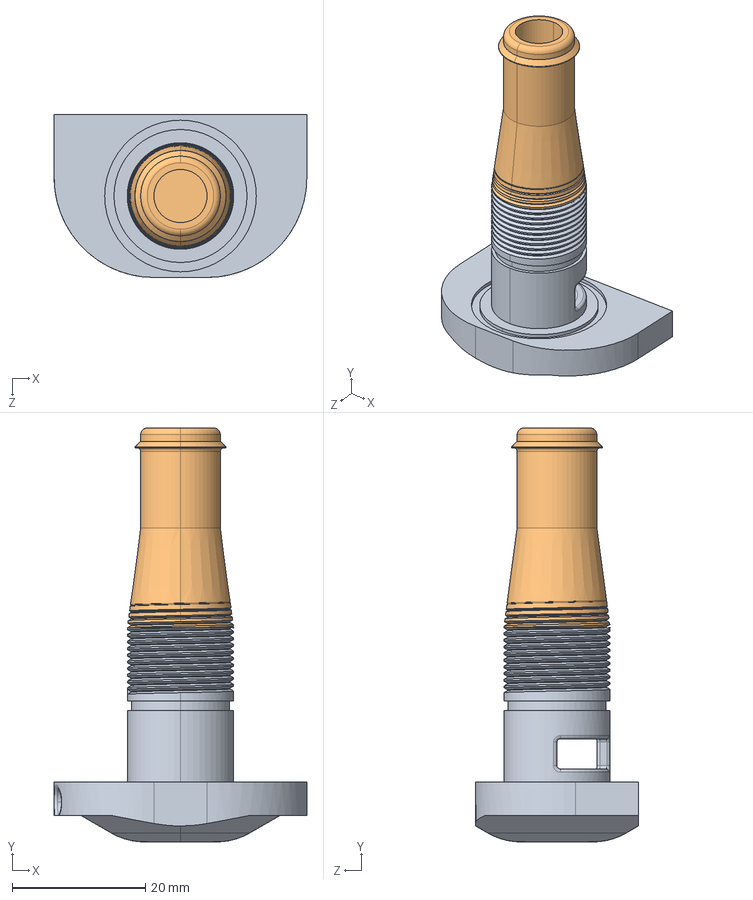
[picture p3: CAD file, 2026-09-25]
cad/C-3P3W827551A_Transfer_Terminate.STEP
38.0 x 62.2 x 24.5 mm

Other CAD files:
cad/C-3P3W827551A_TransferInlet2.SLDPRT
cad/C-3P3W827551A_TransferOutlet2.SLDPRT
cad/C-3P3W827551A_Transfer_Terminate.SLDPRT

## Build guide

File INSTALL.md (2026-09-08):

# Cool Eva — Raspberry Pi installation

Telemetry service for a watercooled Energica Eva Ribelle. This installs the `cool-eva` systemd service, which brings up can0, reads the MAX31865 coolant probes over SPI, decodes the bike's CAN/OBD-II telemetry, and serves the live phone dashboard on port 80. See `README.md` for what it does; this file is just how to get it running on the Pi.

Everything below runs **ON THE PI** unless a step says "on the laptop".

## 0. Hardware

- Raspberry Pi Zero 2 W (or any Pi with SPI + USB).
- 2x MAX31865 + PT100 (4-wire) boards on SPI0:
  - `coolant_in` -> `/dev/spidev0.0` (CE0, inlet)
  - `coolant_out` -> `/dev/spidev0.1` (CE1, outlet)
  - Board reference resistor is 430 ohm (Adafruit); PT100 nominal 100 ohm.
- (Optional) Radiator fan: SPAL VA69A-A101-87S on an IBT-2 / BTS7960 half-bridge, driven from hardware PWM0. Off unless `FAN_ENABLED=1`. Pin map, the `config.txt` lines and the udev rule are in §1 below; the wiring reasoning (why VCC is 3.3 V and not 5 V, why idling pulls both enables low) is in `docs/fan-control.md`.
- 8devices Korlan USB2CAN into the bike's OBD port. Uses the in-kernel `usb_8dev` driver — no driver install. 500 kbit, 11-bit. It presents as can0.
  - ⚠️ **`sudo apt install can-utils`** if you want the raw capture (`can-capture.service`, installed by the setup script). It is not a default package; without it the installer refuses to enable the unit and says so. The capture is what every decode finding in `docs/` was derived from — see [`docs/can-capture.md`](docs/can-capture.md).
- (Optional) Energica Connectivity Hub reached over BLE for torque/power, odometer, vehicle state. The Pi's onboard Bluetooth is fine.

## 1. Base OS setup

Flash Raspberry Pi OS (64-bit, Bookworm or newer) and boot it. Then:

```sh
# Enable SPI for the MAX31865 probes
sudo raspi-config nonint do_spi 0
# (or: raspi-config -> Interface Options -> SPI -> Enable, then reboot)

# Confirm SPI came up after reboot — you want spidev0.0 and spidev0.1
ls -l /dev/spidev0.*

# Confirm the Korlan shows up as a CAN interface once plugged in
ip -details link show can0
# If it's missing, check:
dmesg | grep -i usb_8dev
```

The app itself brings can0 up (down -> set bitrate 500000 + active -> up) at startup, because it runs as root. You do NOT need to configure can0 in `/etc/network` or systemd-networkd. It **skips** that down/up when the interface is already running at 500 kbit with `restart-ms 100` and the mode it wants, because the down kills every other socket on the bus — see [`docs/can-capture.md`](docs/can-capture.md). The startup log line says which path it took and why; ⚠️ that the skip fires on this hardware is unconfirmed until you have read that line once.

**Cooling fan (skip unless you wired the IBT-2 — §0).** Unlike SPI, this needs `/boot/firmware/config.txt` edited by hand:

```sh
sudo tee -a /boot/firmware/config.txt <<'EOF'
dtoverlay=pwm,pin=18,func=2
gpio=17,op,dl
gpio=27,op,dl
EOF
sudo apt-get install -y raspi-utils   # provides `pinctrl`, which drives the two enables
sudo reboot                           # an overlay is not applied at runtime

# After the reboot — a PWM chip should exist. The NUMBER varies by kernel; the app
# discovers it and logs which it picked, so do not hardcode 0 anywhere.
ls /sys/class/pwm
```

The two `gpio=` lines pull the IBT-2's enables low at boot, so a Pi that is booting or has crashed leaves the bridge in standby rather than driving the fan. They are not optional.

**No `dtparam=audio=off` is needed on a Zero 2 W**, whose device tree declares `audio_pins` empty — `dtparam=audio` there toggles HDMI audio only. §0 invites any Pi with SPI and USB, though, and on a Pi with an analogue audio jack (3, 4) `audio_pins` is `<40 41>` at Alt0, which _is_ PWM0/PWM1: on those, add `dtparam=audio=off` to the block above. `docs/fan-control.md` §5.

`/sys/class/pwm` is root-only and the service runs as root, so nothing more is needed for it. To drive the fan as `pi` (or if you ever run the service unprivileged) add the udev rule in `docs/fan-control.md` §5 — including its second stanza, without which the exported channel's own files stay owned by root.

## 2. Node.js 24

The service runs TypeScript directly via Node's `--experimental-strip-types`, so you need Node 24.x. If it's not already installed:

```sh
curl -fsSL https://deb.nodesource.com/setup_24.x | sudo -E bash -
sudo apt-get install -y nodejs
node --version # expect v24.x
```

Build tools for the native modules (better-sqlite3, socketcan):

```sh
sudo apt-get install -y build-essential python3 git
```

## 3. Get the code

Deploy convention is a git checkout at `/home/pi/cool-eva`, owned by `pi`:

```sh
# Public fork — nothing to configure, the Pi only ever pulls:
git clone https://github.com/<your-fork>/cool-eva.git /home/pi/cool-eva

# Private fork — keep the ssh remote and see the note below:
git clone git@github.com:<your-fork>/cool-eva.git /home/pi/cool-eva

cd /home/pi/cool-eva
```

**⚠️ Never `sudo git pull` in this checkout.** A pull as root leaves root-owned files in `.git`, and the next pull as `pi` then fails — _silently_, so the service restarts on the old commit while the journal looks healthy. If it has already happened: `sudo chown -R pi:pi /home/pi/cool-eva`. The dashboard's Update button pulls as the checkout's owner for exactly this reason, even though the service itself is root.

**Which remote.** Because the pull runs as the owner, `pi`'s own ssh setup is in reach and there is nothing special to configure: a **private** fork keeps its `git@github.com:…` remote and uses `pi`'s deploy key at `/home/pi/.ssh/id_ed25519` the ordinary way. A **public** fork can use the https URL and needs no key at all. What does _not_ work is pulling as root with `HOME` pointed at `/home/pi` — OpenSSH expands `~` from the effective uid, not `$HOME` — which is why the button used to fail with `Host key verification failed.` while a pull as `pi` worked fine. `scripts/setup-service.ts` checks both the ownership and the remote at install time.

[`docs/deploy.md`](docs/deploy.md) has the full reasoning, the 2026-09-08 incident it comes from, and the measurements behind it.

## 4. Install dependencies

```sh
cd /home/pi/cool-eva
rm -f package-lock.json # IMPORTANT — see note below
npm install             # builds better-sqlite3 + socketcan (~4 min)

# Verify the Linux-only native CAN module actually built:
ls node_modules/socketcan/build/Release/can.node
```

**WHY rm the lockfile:** `package-lock.json` is committed but generated on macOS, where socketcan (a Linux-only optionalDependency) is skipped. Installing on the Pi against that lockfile prunes the real native build and the service then dies on boot with `ERR_MODULE_NOT_FOUND: socketcan`. `npm install socketcan --force` will not fix it — it insists it's already up to date. The reliable fix is `rm package-lock.json && npm install` on the Pi.

Only re-run `npm install` on the Pi when a dependency actually changed; a plain `git pull` never touches `node_modules` and is always safe.

## 5. Encrypted ride log key (do this on the laptop)

The Pi is given a PUBLIC key only, so a stolen SD card yields ciphertext. On the laptop:

```sh
node --experimental-strip-types scripts/generate-log-key.ts # writes both keys

# BACK UP the PRIVATE key (password manager). It is the ONLY thing that can
# ever decrypt the logs. Lose it and every logged ride is gone forever.

scp ride-log-key.public.pem pi@cool-eva.local:/home/pi/cool-eva/
```

The service looks for `ride-log-key.public.pem` in the project dir by default (or set `RIDE_LOG_PUBKEY`). Without it, logging still runs but is not encrypted.

## 6. Configuration (environment variables — optional)

Defaults are correct for a stock bike; skip this section unless you need one. All are read by `src/index.ts`:

- `FAN_ENABLED=1` — drive the IBT-2 cooling fan and serve `/fan`. **Opt IN**, unlike every other flag here: unset means no `/sys/class/pwm`, no `pinctrl`, no endpoint. With it set the fan follows the pack temperature automatically from boot. Needs the §1 `config.txt` lines first. See `docs/fan-control.md`
- `CAN_ENABLED=0` — skip CAN entirely (coolant only)
- `OBD_ENABLED=0` — passive/listen-only: decode broadcasts, don't TX OBD polls
- `ELOCK_ENABLED=0` — skip the one-shot keys-paired read from the E-LOCK ECU
- `BLE_ENABLED=0` — skip the Bluetooth link to the Connectivity Hub
- `BLE_MAC=<addr>` — pin the hub's BLE address (default: discover by name)
- `GPS_TIME_SYNC=0` — never step the system clock from satellite time
- `CUSTOM_BMS_CONFIG=1` — ONLY if the pack's LiBAL BMS is flashed with the custom config. Leave UNSET on a stock Energica. See README.
- `RIDE_LOG_PUBKEY=…` — path to the X25519 public key (default: `./ride-log-key.public.pem`)
- `RIDE_LOG_DIR=…` — where sealed `.celog` segments go (default: `./ride-logs`)
- `VCU_PARAM_DIR=…` — where read-vcu-params.ts snapshots live (default: `./vcu-params`)

The install script (next step) does NOT bake env vars into the unit. To set any, add a systemd drop-in AFTER installing the service:

```sh
sudo systemctl edit cool-eva
# then add, e.g.:
# [Service]
# Environment=CUSTOM_BMS_CONFIG=1
sudo systemctl restart cool-eva
```

## 7. Install and start the service

```sh
cd /home/pi/cool-eva
sudo node scripts/setup-service.ts
```

This writes `/etc/systemd/system/cool-eva.service` (running as root, so it can bring up can0), then enables it at boot and starts it. Upgrading a Pi from before the 2026-08 rename needs nothing by hand — the script stops, disables and deletes the old `thermometer` unit itself. Useful commands it prints:

```sh
sudo systemctl status cool-eva     # check status
sudo journalctl -u cool-eva -f     # follow logs
sudo systemctl stop cool-eva       # stop
sudo systemctl disable cool-eva    # remove from boot
```

On a healthy start the logs show, roughly:

```
can: can0 up @500k — ACTIVE (TX enabled)
coolant: 2 MAX31865 probe(s) started (sensor-rate polling)
ride-log: encrypting to … (only if the public key is present)
```

## 8. Reach the dashboard

The service serves the live dashboard on port 80. From a browser on the same network:

```
http://<pi-ip>/
# or, with mDNS:
http://cool-eva.local/
```

For the `cool-eva.local` name you need the hostname set and Avahi running:

```sh
sudo hostnamectl set-hostname cool-eva
sudo apt-get install -y avahi-daemon
```

Networking note (from README): the intended setup is the Pi joining a phone's hotspot so it's reachable at http://cool-eva.local while riding/charging.

Endpoints: `/dl` (sealed ride-log download), `/waypoint` (Siri shortcut), `/status`, `/vcu-params` + `/params.html` (last VCU-param snapshot, never touches bus), `/fan` (cooling-fan duty and mode — only with `FAN_ENABLED=1`, otherwise a 404; a POST needs `X-Cool-Eva: fan`).

## 9. Deploying updates later

The dashboard menu's **Update** button does this for you: it runs `git pull --ff-only` in `/home/pi/cool-eva` **as the checkout's owner, not as root** (see §3), shows git's output, then restarts the service so the new code takes effect. The WebSocket drops on restart and the dashboard reconnects on its own. It does **not** run `npm install`, so use it only for code changes.

By hand (or when a dependency changed):

```sh
cd /home/pi/cool-eva
git pull
sudo systemctl restart cool-eva

# ONLY if a dependency changed:
rm package-lock.json && npm install
# then re-verify node_modules/socketcan/build/Release/can.node exists
```

Notes:

- Restarting the service re-initialises can0, which kills any other raw-CAN socket (scratch scripts) with `OSError 100 Network is down`. Expected.
- The Connectivity Hub accepts one BLE connection at a time and the service holds it. Stop the service before running a scratch BLE probe.
- There's no reception in the garage; the Pi is only reachable when parked in wifi range.

## 10. Setting up config file for cool-eva

On my Raspberry Pi, ensure `EnvironmentFile` is set up in the service unit:

```ini
[Service]
Type=simple
WorkingDirectory=/home/pi/cool-eva
EnvironmentFile=/etc/default/cool-eva
ExecStart=/usr/bin/node --experimental-strip-types /home/pi/cool-eva/src/index.ts
Restart=on-failure
RestartSec=5
User=root
```

Then create `/etc/default/cool-eva`:

```sh
COOLANT_ENABLED=0
BLE_MAC=<mac address>
SERVICE_WRITE_ENABLED=1
CUSTOM_BMS_CONFIG=0
```

## 11. Quick tips on bringing CAN back online

If you are troubleshooting and rebooted the Pi but the can0 interface looks down, you need to bring it back up manually or reboot the bike:

```sh
ip -details link show can0
ip link set can0 type can bitrate 500000
ip link set can0 up
ip -details link show can0
```

## 12. Optional: Grafana on the laptop (post-ride analysis)

Grafana runs on the LAPTOP, not the Pi. Download a sealed log from the Pi, then:

```sh
node --experimental-strip-types scripts/decrypt-log.ts <file>.celog --out temperatures.db
docker compose up -d # Grafana at http://localhost:3000
```

See `README.md` "Encrypted ride log" and "Grafana" for the datasource caveat (temperatures.db vs rides.db) and dashboard details.

## Safety

The CAN bus is read-only here: passive broadcast decode, standard OBD-II READ requests, and KWP 0x22 parameter reads. No writes of any kind. Only touch hardware you own and are authorized to modify.

With `FAN_ENABLED=1` the fan starts **on its own** whenever the pack is warm, and the dashboard can start it from a phone with one drag — there is no two-tap arm on it (`docs/fan-control.md` §4 "The slider"), only the `X-Cool-Eva: fan` header a POST needs. Keep fingers out of the duct while the Pi is powered: a `SIGKILL` leaves the bridge driving until the service restarts itself, which `Restart=on-failure` / `RestartSec=5` makes about **five seconds** later — long enough to matter with a hand in the duct, and only that long because the unit restarts (`docs/fan-control.md` §8).

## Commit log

2026-09-08 Regen is the green half of the power bar, and the BMS's ceilings are on it (#137)
    * Regen is the green half of the power bar, and the BMS's ceilings are on it
    Two things about the riding screen's power bar.
    **The colour was inverted.** `colors.power()` tested `kilowatts < -0.5` for
    its green, which is the sign convention read backwards: `pack_kw` is negative
    under discharge and positive on regen and charge, as derive.js asserts by name
    precisely so this cannot happen. So a 100 kW pull was painted green and a
    20 kW recovery amber — since 2026-08-03 (#33), under a doc comment that said
    "regen is always green (energy coming back), drive ramps with load" correctly
    the whole time. Nothing cat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
2026-09-08 The power bar hatches what the pack has taken away (#139)
    * Hatch the power the pack has taken away, and scale each half to its own direction
    Follow-up to #137, on the maintainer's reading of what the bar should do: a
    Tesla-style meter whose scale never moves, where the part you can no longer
    reach is dashed out. #137 drew a single dashed LINE at each ceiling instead,
    which is a different thing — a line answers "where is the limit" and leaves
    the rider to measure the gap at 90 km/h; hatching answers "how much has gone".
    **Hatching retires both end cases the line needed.** A ceiling wider than its
    half now hatches nothing, which is exactly true — the pack is not what is
    limiting you. Th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
2026-09-08 Map the route driven and the charge stops on it (#140)
    A Geomap of the route with charge stops on it, plus tables that drill down into the Charging,
    Charge manager and Ride summary dashboards with the range already set. Findings in
    docs/route-map.md.
    - gps_lat and gps_lon are separate log-on-change signals sharing a timestamp for only 82.5 % of
    latitude rows, so each is carried forward onto the other's rather than inner-joined.
    - The track is POINTS, not a route line. A line joins every point in the frame, so a multi-ride
    window draws a straight line across country the bike was on a trailer for, and it cannot be
    broken: the route layer renders series[0] and breaks, and NULL break-row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
2026-09-08 The dashboard follows the bike's own day/night mode (#149)
    * The dashboard follows the bike's day/night flag, and gets a light theme
    The phone dashboard is unreadable in direct sun. The bike's own dash switches
    day/night, and it turns out that state is on the bus: 0x400 b5 bit 7, which
    Energica's free-frame IO table calls `DBS DAY/NIGHT MODE` and which nothing had
    decoded. Measured over the whole archive — 14 069 994 frames across 97 captures,
    12.8x the corpus the 0x400 section was written on — it is set in 77.3 % of
    satellite-validated daytime frames and in 0 of 2 258 235 validated evening ones,
    is independent of both beams, and flips within ~90 s of the bike leaving a dark
    garage on a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
2026-09-08 The Update button tells you why it failed, and the Pi pulls over https (#148)
    * The Update button tells you why it failed, and the Pi pulls over https
    The dashboard's Update button failed with "Host key verification failed."
    The service runs as root, and update.ts tried to borrow pi's ssh credentials
    by setting HOME=/home/pi on the git pull. That never worked: OpenSSH expands
    ~ from the effective uid's passwd entry, not from $HOME, so root's ssh read
    /root/.ssh whatever HOME said. Verified: `HOME=/nonexistent ssh -G github.com`
    still prints the real known_hosts path.
    Drop the override, make https the documented convention for the Pi (root
    never pushes, the repo is public), and say why in I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
2026-09-08 Replace the BMS's unusable pack resistance with a live regression (#144) (#151)
    * Replace the BMS's unusable pack resistance with a live regression (#144)
    `pack_resistance_mohm` (0x206 b0-1) drove five derived quantities and is not fit
    to. Across the full 15.4 M-row history it has 301 rows: 41 % zero, 46 above
    1000 mOhm, frozen for hours, and it produced nothing at all across a 52-minute DC
    charge. DC_CHARGE_LIMITS.md had already diagnosed it as a dV/dI estimate that
    divides by ~zero on a flat plateau — which is exactly a steady charge.
    The sparsity is the BMS, not the logger: 0x206 arrives at a clean 1.00 Hz in the
    2026-08-02 capture with b0-1 reading 0 in all ninety frames.
    Replaced b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
2026-09-08 Four weeks after the clear, the trailing byte answered (#159)
    * Four weeks after the clear, the trailing byte answered
    First session with the bike connected since the freeze-frame work landed. Four
    findings, all measured.
    The trailing byte on a 0x17 reply is a saturating occurrence counter. The two
    readings made opposite predictions and only one survived: components 44, 51, 52
    and 60 all read FF before the 2026-08-09 clear and read 08/05/05/05 today, and 53
    went 07 to 01. A counter resets and recounts; a "not applicable" sentinel does not
    become 5 because someone cleared codes. What is worth noting is that this closes
    the question DESPITE the compromised test rather than by escaping it —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
2026-09-08 Diagnose the DC set-current failure, stop the charge tab flickering, and make the feature prove itself (#153)
    * The dash's own DC charge pair, captured — and what actually broke on 09-07
    On a DC fast charge on 2026-09-07 the set-current control changed the number on
    the bike's dash and moved no current at all. The cause was not the protocol: the
    Pi was running 93e071a, pulled 2026-09-03 20:29 CEST, and the 0x120 commit twin
    landed in 676d95f at 22:34 the same day. It spent five days sending the 0x121
    half alone — the half docs/can-0x121-charge-command.md had already proven does
    not commit.
    Everything about the pair had been proven on AC (0x1A, ceiling 0x0F); the DC
    layout was asserted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
2026-09-08 The annotated preview's close-ups frame the block their caption names (#161)
    * The annotated preview's close-ups frame the block their caption names
    Every close-up panel of the design-review sheet has been broken since
    2026-08-27, and `npm test` was green for all twelve days.
    The panels scope themselves to one block of the write section with
    `:nth-child(5) > :nth-child(1|2|3)`, written in b98e019 when VcuWrite()
    held three blocks. It has held six since 7c1df26, a17bddd and 213f7fc
    added the headlight, reset-VCU and all-lights controls. So the close-ups
    framed blocks their captions did not describe — "The fold, shut" showed
    Reset VCU — and the shape guard in front of them rejected after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
2026-09-08 Correct six claims from #159 — three of them settled on the bike today (#169)
    * Correct six claims from #159, three of them measured on the bike today
    A review of #159 after it merged found nine defects. These are the ones settled by
    new measurement rather than argument; the bike was on for the freeze-frame and
    bank-2 reads.
    The DTC clear is dated wrong. The archive holds exactly one 7C0 14 FF FF request in
    every capture on disk and it is 2026-08-08 19:04:28, not 2026-08-09 14:42:32. The
    08-09 hits a naive grep finds are payload bytes inside GPS 0x410 frames. Worse,
    14:42:32 that day is a real timestamp for an unrelated event -- a charge-manager
    fault clearing during the aborted DC attem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
2026-09-08 Fix four measurement nits from the #169 review (#174)
    * Fix four measurement nits from the #169 review, one of them a units error
    "60x the sample" was wrong and wrong in the way this document keeps warning about:
    it compared 37 288 frames against §12's 597 rising edges. At 100 Hz one ~10 ms pulse
    is one frame or several, so frames are not events. Like for like the archive gives
    742 rising edges against 597, which is 1.24x -- and even that overstates it, because
    §12 read rides.db while this reads the capture archive and the two corpora overlap
    heavily. Much of the 742 is likely the same events counted twice through different
    pipelines. The sweep is a reproduction of §12, not a bigger samp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
2026-09-08 Taking the auto charge controller back after a manual change is one tap (#176)
    * Taking the controller back after a manual change is one tap
    Closes #175. Daniel, reading #163: "there needs to be a way to re-enable it
    after a manual change WITHOUT restarting the charge session."
    The path existed but was hidden, and the label pointed the wrong way. While
    stood down the effective mode is still `automatic`, so the button read "Switch
    off for this charge" — the opposite of what the rider wants — and taking the
    controller back meant tapping OFF and then ON: two taps through a state that
    says the wrong thing.
    The button has three states now, not two. When the reason is RIDER it reads
    "Take t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
2026-09-08 The service-stamp read answers where you pressed, and the journal survives a hole (#172)
    Daniel pressed "📖 Read the last-service stamp" on 2026-09-08 at 14:17 and
    reported "it doesn't seem to change anything". The read had worked, twice.
    WHERE THE ANSWER WENT. The outcome sentence was written to `message`, whose
    only home on a sheet with controls is Outcome() — three sections and ~600 px
    up an overflow-y sheet from the button that asked — and set as a bare
    .action-note: 11.52 px in --label, the same type as the static grey line
    describing what the button does. So the answer to the one question the control
    exists to ask rendered off screen, in the quietest type on the page.
    The read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
2026-09-08 Read the lifetime statistics in-service — and measure whether the service can (#177)
    * Correct the trailing byte's wording and the clear's date, per #169
    Four sites from PR 1 assert KEY CYCLES for the freeze-frame trailing byte. The
    second read of 2026-09-08 does not support that: five components advanced by
    exactly +1 across an interval that held BOTH a VCU reset and a key-off/key-on,
    so they moved +1 rather than +2 and whether a reset alone counts is unresolved.
    "Cycle" means at least one of those two things happened.
    Corrected in src/diagnostics/freeze-frame.ts, src/diagnostics/lifetime-stats.ts
    and scripts/captured-freeze-frames.ts, plus the three check and summary strings
    that repea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
2026-09-08 Track the raw CAN capture, and make it survive an interface bounce (#160) (#185)
    * Bring the raw CAN capture into the repo, and make it survive a bounce (#160)
    `can-capture.service` and `capture.sh` were tracked NOWHERE — one copy on one
    SD card, no revert path, no review — while producing the corpus that nearly
    every decode finding in docs/ rests on. They are here now, reproduced from the
    2026-09-08 gather with one functional change each.
    capture.sh: `candump -D`. The socket stays bound with its filters registered
    when can0 goes down (net/can/raw.c raw_notify: NETDEV_DOWN sets ENETDOWN and
    nothing else), so frames resume by themselves and the SAME file keeps being
    written. Only NETDEV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
2026-09-08 Make the preview harness faithful enough to gate a dashboard merge (#184)
    * Make the preview harness faithful enough to gate a dashboard merge
    The dashboard-merge rule is that someone looks at real screenshots first,
    and the instrument that produces them was blind on every panel added in the
    last week — and lying about two more.
    - WRITE_STATUS gains runningVersion and chargeAck, and loses gate.readings,
    clock.reasons and run.expected, none of which the Pi sends. runningVersion
    is the one that mattered: vcu-write.js destructures it, the binding threw,
    and VanJS left Availability()'s "waiting for an answer" ellipsis in place —
    so twelve days of screenshots silently lacked the saf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
2026-09-10 Correct six statements #197 shipped about the press archive (#208)
    * Correct six statements #197 shipped, one of them a quote of a line that does not exist
    Found by the fresh-context diff reviewer on #197, which finished after the
    merge. Prose and one check label; no logic changes.
    1. docs/handlebar-gestures.md quoted can_log-2026-06-14.txt's first frame as
    `1781428137.328 102 8010…`. No such line exists: `.328` carries ids 447 and
    620, and the file's first 0x102 frame is
    `1781428137.333 102 0002004499ffddff`. The timestamp came from one record
    and the data bytes from a different file's format. The same paragraph
    argues that a can0-anchored grep drops this file, and ten li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
2026-09-11 Let the fan stay off through a creep, and say so (#210)
    * Let the fan stay off through a creep, and say so (#205)
    Daniel, day 2: he silenced the fan in a toll queue to hear the booth, and
    again on a hotel forecourt while manoeuvring and being talked to. Both times
    it was back at full before the conversation the silence was for.
    *Off* could only be entered at 3 km/h and was handed back on the first
    sample above it. The 3 was the bike's own number — its dash menu is
    stationary-only and exits above 3 km/h — which is a true fact answering the
    wrong question: the rider wants the fan quiet when the noise is in the way,
    not when the bike thinks it has stopped, and those come apart the moment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
2026-09-18 A return out of the 54 °C band is not permission to raise (#280) (#283)
    * A return out of the 54 °C band is not permission to raise (#280)
    `src/charge/pace.ts` released a pending raise when the reading had FALLEN
    since the last command. Measured over every crossing into 55 on record — 56 of
    them — that is wrong for the case it fires in most: 31 of the 50 charging
    crossings return 55 → 54 inside about a minute with ~50 A still flowing, which
    no conductance model calls cooling. It is the hottest cell's saw-tooth, whose
    period is 1.6 min across all charging crossings and 1.2 min in the 54 band, and
    read as permission it hands the rule a raise straight back into the band. The
    cost is th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
2026-09-18 The fan curve never froze: #282's 42 minutes are four boots read off one clock (#286)
    * The fan curve never froze: #282's 42 minutes are four boots read off one clock
    Issue #282 reported the automatic curve stuck at 68 % for 42 minutes on
    2026-09-09 while the pack climbed 43 -> 55 C and crossed the thermal cliff four
    times at 58-65 A. It did not happen. The rows come from four different boots of
    the service spliced onto one `ts` axis: the 68 % belongs to a boot that lived 90
    seconds and never saw a delivered amp, and the whole climb belongs to a boot
    that held `fan_auto_reason` = DC_SESSION at 100 % from its first tick until the
    ride home.
    Neither reported defect is real. What is real is t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
2026-09-19 The Pi stopped asking: record the wifi, and dump it where it can be read (#290) (#291)
    * The Pi stopped asking: record the wifi, and dump it where it can be read (#290)
    NetworkManager latched the hotspot profile out of autoconnect on 2026-09-19
    and sat disconnected for twenty minutes. The Pi is reachable only over the
    wifi that was failing, so nothing recorded it.
    Diagnosis (docs/wifi.md, verified against NetworkManager 1.52.1's own source):
    six re-associations to a BSSID the iPhone had already discarded — it
    randomises the hotspot MAC every restart — were read as a wrong PSK, and on a
    headless Pi with the key in the keyfile and no secret agent, `asking for new
    secrets` can only end in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
2026-09-19 The watchdog is the fix, the thumb is the override (#290) (#303)
    * The watchdog is the fix, the thumb is the override (#290)
    PR 1 gave the bike eyes: three polled wifi_* signals and a diagnostic dump
    after two minutes of "disconnected while the hotspot is in range". This gives
    it hands — the same trigger now runs a recovery, and a handlebar hold runs the
    identical path on demand.
    Ladder: dump, then `nmcli device wifi list --rescan yes`, then `connection up`
    the hotspot profile BY NAME. The rescan is what answers the stale-BSSID cause
    whichever layer held it (#295 records that layer as still a hypothesis), and
    `--rescan yes` already waits for provably newer results, so there is no
    hand-ro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
2026-09-19 Bound the BLE adapter wedge: recover it, rate-limit it, and write down why a restart cannot (#299) (#301)
    * Bound the BLE adapter wedge: 14 episodes, none ever self-recovered (#299)
    `ble: session failed: Operation already in progress` was 20 632 lines of the
    2026-09-15..19 journal export — 14.9 % of every line, 27 % of its wall clock —
    in 14 episodes, and NOT ONE recovered before its boot ended. It is not the hub
    and not a pending Device1.Connect(): the kernel's discovery state machine is
    stuck, MGMT 0x003a comes back Busy(0x0a) in 25 us with no HCI command emitted,
    and nothing in userspace clears it. Verified on the bike 2026-09-19 22:21:46 —
    a `bluetoothctl power off/on` cleared a 3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
2026-09-19 A fast laptop-side ride map for rides.db (SvelteKit + MapLibre) — phase 1 (#305)
    * Where the ride map's numbers come from, and the two that were wrong (#296)
    The plan for a laptop-side viewer rests on measurements that move: the same
    query over this 4 GB archive measured 12 900 ms and 280 ms an hour apart, and
    two revisions of #296 were built on one end of that range. This is the
    provenance CLAUDE.md wants out of the issue body and into docs/ — including the
    43.8 us/lookup "constant" that does not exist, the rAF cadence that was read as
    a frame rate, and the scatter measurement that replaced the first of them.
    Nothing here changes behaviour; no code has been written for #296 yet.
    Co-A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
2026-09-19 GPS gaps: what CAN can and cannot fill (#309) (#313)
    * GPS gaps: position is on CAN already, and 330 h of the holes are a parked bike (#309)
    Answers Daniel's question "for the segments where we don't have GPS data cuz the
    BLE connection dropped — it's not recoverable from our CAN dumps?". No, and the
    premise was wrong twice: position has been on CAN 0x410 since #22, independent of
    BLE, and 270 of 316 dark windows are a stationary bike behind gps_lat's 3.3 m
    deadband rather than lost position.
    Where position really is missing, the bus usually is too — on the five days we
    hold captures, 5.8 km of 56.0 dark km had a fix on the bus that never reached the
    log. The archive's largest window (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
2026-09-20 Ride map phase 1.5: marker toggles, satellite, charge tooltips, click-to-fly (#312)
    * map/: marker toggles, satellite, charge tooltips and click-to-fly (#296)
    Phase 1.5, the four things Daniel asked for after testing the merged viewer.
    SATELLITE IS EOX BY DEFAULT, MAPTILER WHEN A KEY EXISTS. ⚠️ My first plan
    rejected EOX because a licence page "would not load" — the hostname I tried,
    docs.eox.at, is NXDOMAIN. It was invented, it failed, and I wrote the failure up
    as evidence about someone's licensing. The real source settles it without that
    page: EOX's own WMTSCapabilities.xml answers 200 with NO KEY and says each
    s2cloudless layer is "released under Creative Commons BY-NC-SA 4.0", w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
2026-11-03 Codex reads AGENTS.md, so point it at CLAUDE.md (#316)
    The repo's conventions live in CLAUDE.md, which Claude Code loads and Codex
    does not: Codex looks for AGENTS.md. Lanes now run on Codex, so without this
    they work without the house rules (no *Sync calls in the app, never swallow
    errors, monotonic durations, the Pi deploy hazards).
    A symlink rather than a copy, so there is one file to keep current.
2026-11-03 README a new rider can follow; reference moves to docs/ (#326)
    From Daniel's AI agent. Rewrites README.md around what a new rider installing a Pi and a Korlan needs, moves the technical reference into docs/ (every moved range preserved, links and source-comment anchors repaired), adds docs/cooling-hardware.md for the optional coolant probes and radiator fan, offers a ZIP download for computer setup, restores the Pi lockfile after the first native build so Update keeps working, and marks the environment-variable instructions that #317 replaces.
    Refs #321.
2026-11-03 README: show the phone dashboard (#333)
    From Daniel's AI agent. Adds Ride, Charge and Faults screenshots of the phone dashboard to the README, rendered from synthetic sample data and losslessly compressed (128 KiB total). The #183 redesign refreshes them when it ships.
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2026-11-03 Harden the Bluetooth dashboard server (#332)
    From Daniel's AI agent. Hardens the opt-in BLE tunnel from #315 before BLE_SECRET is switched on: only complete single frames before authentication, one verified owner with release on disconnect or bluetoothd restart, the HELLO proof checked before any owner action, bounded inbound and outbound work, a notification bound of MTU−5, a 64-hex generated key instead of a typed password, no lockout or secret blacklist, a session drop on authenticated silence, an exact origin allow-list for saved codes, no advertised name, immediate logging of internal failures, and the protocol rationale kept in docs/ble-server.md. Address privacy stays off pending a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
2026-11-04 Settings phase 2: startup-applied settings and dashboard Settings (#336)
    From Daniel's AI agent. Phase 2 of #317. Activates the one-time migration from the service's environment and the journalled data move to /var/lib/cool-eva on first start, before any writer runs. Replaces the runtime environment switches with saved settings that apply at the next explicit, bus-reserved restart. Adds the approved Settings map with compact actions, pending and active states, hardware readiness and configuration faults. readEnvFile is removed, and every mutating route carries a CSRF barrier. Refusal paths keep old folders readable over ssh, a bad legacy field faults only itself, and an old Siri waypoint sho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
2026-11-04 Easy setup step 2: release-bundle updater with automatic rollback (#335)
    From Daniel's AI agent. Second increment of #324: a shell updater that installs a verified release bundle into an atomic current/previous layout. The new release runs a 60-second trial and rolls back automatically on a crash loop or start-limit failure, with one shared lock, explicit rollback targets and settings restored only when the old code cannot read them. Recovery fails open, so an updater fault never stops the app. Edit archives and settings snapshots are bounded. The bundle Update takes the same parked and bus-lease reservation as the checkout Update right before stopping the app, and otherwise refuses with the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
2026-11-04 Disarm dashboard actions when changing views (#340)
    From Daniel's AI agent. Arming Stop charging, switching to another screen and coming back left the old confirmation armed, so one more tap could stop the charge. Every tab change now clears the shared confirmation: tab taps, the handlebar gestures, automatic moves, Back/Forward and hash changes. A node check and a headless-browser check (arm Stop, go to All and back; the first tap sends nothing) guard it, and both fail with the fix removed.
    Refs #183.
2026-11-04 Dashboard: Cooling navigation, compact notices and real inset gate (#341)
    From Daniel's AI agent. First slice of the #183 riding-screens redesign. Cooling becomes a sub-tab of Ride (#ride/cooling) and a stop in the handlebar cycle (Ride → Cooling → Range → Charge → All → Faults). The header is 52 px plus the phone's top inset. Pending notices (fault, then reload, then setup, with a count) collapse into one tappable line in the header that opens Settings, and the full text lives there, so a notice never pushes riding content down. Cooling's fan line uses the fan screen's wording, including the braking fault. Availability of the on-demand fan signals follows presence, fault and link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
